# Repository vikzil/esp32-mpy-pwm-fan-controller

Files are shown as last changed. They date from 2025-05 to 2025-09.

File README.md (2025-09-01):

# esp32-mpy-pwm-fan-controller
MQTT-Enabled PWM Fan Controller with 6 Thermistor sensors and MicroPython on ESP32

# Disclamer
I am a hobbyist and not a professional when it comes to electronics or programming. While I try to ensure accuracy, there may be mistakes or suboptimal choices in my work. Please use this as a learning resource, and feel free to offer corrections or suggestions for improvement!

# Background
The purpose of this repository is to document, share, and hopefully polish over time an ESP32-based MicroPython PWM fan controller using thermistors. I created this project to monitor the temperatures of up to six hard drives in my DIY NAS.

In most PCs, fans are controlled based on CPU or GPU temperatures, but that’s not ideal for managing HDD temperatures. In my NAS, the drives usually idle cool, but during operations like scrubs or backups—where several terabytes of data are read continuously—they start heating up. That’s where this controller comes in: it monitors HDD temps and ramps up dedicated fans as needed to keep them in a safe range.

The system publishes fan duty, RPM, and temperature readings over MQTT, allowing integration with platforms like Home Assistant for monitoring and automation.

# Schematics
[Fritzing schematic file](schematics/schematics.fzz)

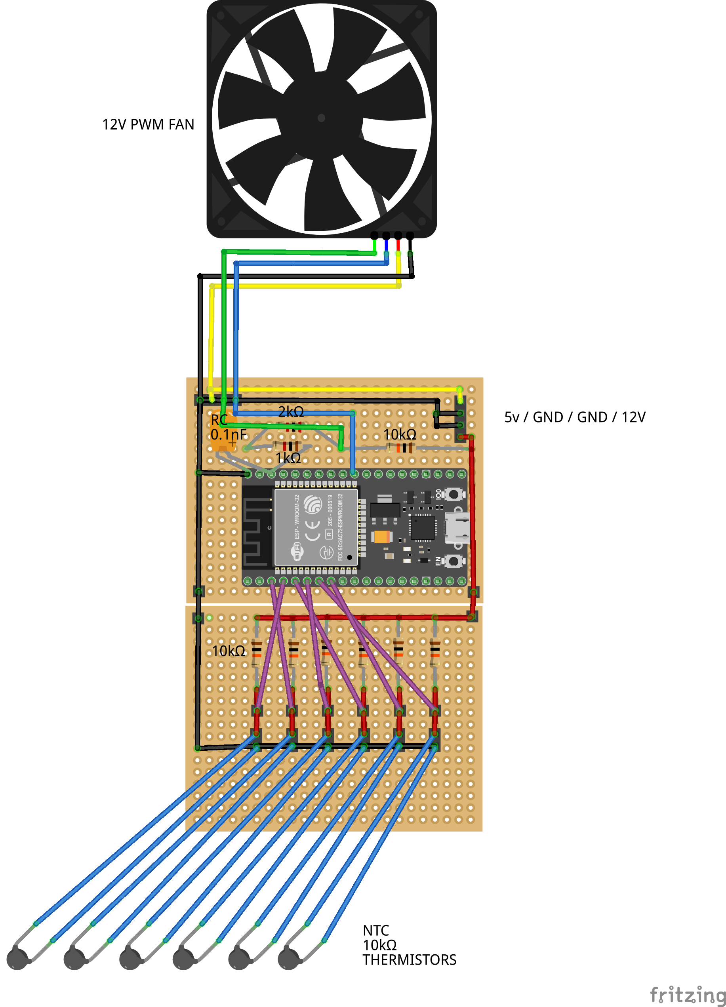
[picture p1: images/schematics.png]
[](images/schematics.png)

# Parts list
* 1× ESP32 controller
* 1× 12V PWM fan (additional fans can be chained if they have compatible connectors)
* 6× 10kΩ NTC thermistor temperature sensors
* 7× 10kΩ resistors
* 1× 2kΩ resistor
* 1× 1kΩ resistor
* 1× 0.1 nF ceramic capacitor
* 1× 4-pin male fan connector
* 1× 4-pin male power supply connector (3-pin could also be used)
* 2× 18×24 hole prototyping PCB boards
* 1× SATA to Molex power adapter (Molex connector removed and wired directly to PCB power input)
* 24 AWG wire
* 1x aluminium tape (I believe it helps with heat transfer between hdd and sensor)

Comments:
* **Casing:** A casing is useful to facilitate handling the fully assembled project and prevent accidental shorts. I used an old external HDD casing, filled it with construction adhesive, and glued the assembled PCBs into it. After that, I waited a couple of weeks to ensure the adhesive had fully dried.
* **USB Access:** I had to cut one edge of the casing to connect a USB cable to the ESP32 for testing. This would have been easier to do before assembling the project.
* **Wires for Sensors:** For attaching the sensors, I used approximately 1m-long wires to ensure the sensors could reach anywhere in the PC case. However, with six sensors, the wires became quite a mess. It might have been smarter to use thinner wires and add connectors to the PCB so sensors not in use could be easily detached.
* **ESP32 Reset:** It would also have been helpful to include a cable with a reset button to easily reset the ESP32 without needing to restart the PC (if powered via SATA, as in my case).
* **Placement:** The placement of the project needs consideration. For example, the ESP32 will lose Wi-Fi connectivity if placed inside a metal PC case. It's better to choose a case with at least one plastic or glass side panel for better connectivity.

# Rough assembly, installation and usage outline
## Install micropython on ESP32
There are several ways to do this, but I used Thonny. A good guide can be found here:

[Getting started with Thonny MicroPython IDE for ESP32](https://randomnerdtutorials.com/getting-started-thonny-micropython-python-ide-esp32-esp8266/)
## Upload scripts to ESP32
Upload the following files to your ESP32: boot.py, main.py, secrets.py, settings.py, and webrepl_cfg.py.
## Install external library umqtt.simple for mqtt support
You’ll need the umqtt.simple library:

[umqtt.simple on GitHub](https://github.com/micropython/micropython-lib/tree/master/micropython/umqtt.simple)
## Fill out credentials
Open secrets.py on your ESP32 and fill in your credentials (e.g., Wi-Fi and MQTT info).
Open webrepl_cfg.py and set password for webrepl access.
## Test run main.py
You should now be able to run main.py and verify that your ESP32 connects to Wi-Fi and publishes data to MQTT. It should also do this automatically after a reset.
A great tool for troubleshooting mqtt is MQTT Explorer:

[MQTT Explorer](https://mqtt-explorer.com/)
## Assemble project without soldering
Assemble the project on a breadboard without soldering according to parts list and schematic, and make sure it works. In this step you should basically be able to get a fully functional controller.

⚠️ Warning: Before powering the project, double-check all wiring and polarities. A wrongly connected 12V line can easily fry the ESP32 or other components.
## Solder everything and install it into casing
Solder everything together and test. Install fully working controller into a casing. Install it into pc and connect temperature sensors to hdds or whatever it is you want to monitor. Connect PWM fan that should react to temperature changes. 
## (Optional) Monitor PWM Fan Duty, Fan RPM and temperature sensor readings in Home Assistant
Home Assistant should be able to autodiscover the sensors, and you can add then to a dashboard. In my case I currently only have two HDDs that I monitor with pins 33 and 39, the rest of the sensors just lie on the bottom of pc case. Also RPM readings worked initially but stopped working after a while, not quite sure why.

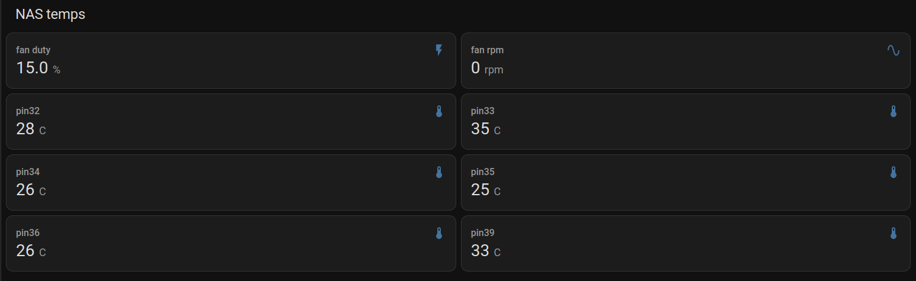
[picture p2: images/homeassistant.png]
[](images/homeassistant.png)

## (Optional) Adjust values in settings.cfg and upload it to ESP32
It's very easy to adjust the PWM fan duty based on temperature while testing the ESP32 in Thonny over USB. However, this becomes more difficult once the controller is deployed in its final location.

The idea is to connect to the controller via WebREPL over Wi-Fi, download the current settings.cfg, modify the values, and upload the file back to the ESP32. After that, simply restart the ESP32 and it should use the updated settings.

[Webrepl over WiFi - Micropython Docs](https://docs.micropython.org/en/latest/esp8266/tutorial/repl.html)

When connected to ESP32 via WebRepl, you should also be able to restart ESP32 by issuing following commands:

Ctrl-C to interrupt printout of temperature readings

<pre>import machine</pre>

<pre>machine.reset()</pre>

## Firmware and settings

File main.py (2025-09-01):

# region import libraries
import gc
import network
import uasyncio
import ujson
import math
from umqtt.simple import MQTTClient
from utime import sleep
from machine import ADC, Pin, PWM
import secrets
# endregion

# region constants
BETA = 3950  # Beta value for thermistor
R_REF = 10000  # Reference resistor value
V_SUPPLY = 5.0  # Supply voltage (5V for ESP32)
DELTA_C = 0 # Temperature measurement correction
THERMISTOR_PINS = [32, 33, 34, 35, 36, 39]  # List of thermistor ADC pins
SETTINGS = {    # PWM Duty depending on max temperature
    0:  30,
    10: 34,
    15: 38,
    20: 42,
    30: 43,
    40: 44,
    50: 45,
    60: 46,
    70: 47,
    80: 48,
    90: 49,
    100: 50
}
# endregion

# Global variables
fan = PWM(Pin(5))  # Fan PWM control
thermistor_temps = {}  # To store temperatures for each pin
temp_C_max = 40  # Initial max temperature
duty = 33.3  # Initial duty cycle
RPM_PIN = 23  # Change if using a different GPIO pin
pulse_count = 0 # Initial pulse count 
rpm = 0 # Initial rpm count


# Initialize thermistors
thermistors = [ADC(Pin(pin, Pin.IN)) for pin in THERMISTOR_PINS]
for t in thermistors:
    t.atten(ADC.ATTN_11DB)  # Set attenuation for full range (0-3.3V)

# Initialize fan
fan.duty(int(duty) * 1023 // 100)  # Initial duty cycle

# Initialize rpm pin with pull-up resistor manually
rpm_sensor = Pin(RPM_PIN, Pin.IN, pull=Pin.PULL_UP)





# region fan control
def set_duty(temp):
    global duty, SETTINGS
    if temp < SETTINGS[0]:
        newduty = 0
    elif temp > SETTINGS[100]:
        newduty = 100
    else:
        items = sorted(SETTINGS.items(), key=lambda item: item[1])
        for i in range(len(items) - 1):
            duty_low, temp_low = items[i]
            duty_upp, temp_upp = items[i + 1]
            if temp_low <= temp <= temp_upp:
                newduty = (duty_low + (temp - temp_low) * (duty_upp - duty_low) / (temp_upp - temp_low))
    if newduty < duty:
        duty = duty - 0.1
        if duty < 0:
            duty = 0
    else:
        duty = newduty
    fan.duty(int(duty) * 1023 // 100)
    print(f">>> Max temp: {temp}°C, setting duty to: {duty}%")
def fan_control():
    set_duty(temp_C_max)
    gc.collect()
# endregion


# region read settings
def read_fan_settings(filename="/settings.cfg"): # try read settings from settings.cfg
    global SETTINGS
    try:
        with open(filename, "r") as f:
            new_settings = {}
            for line in f:
                line = line.strip()
                if "=" in line and not line.startswith("#"):  
                    try:
                        pwm, temp = line.split("=")
                        new_settings[int(pwm)] = int(temp)
                    except ValueError:
                        print(f"Skipping invalid line: {line}")
            if new_settings:
                SETTINGS = dict(sorted(new_settings.items()))
            else:
                print("Invalid file format. Using defaults.")
    except OSError:
        print("Error: settings.cfg not found. Using defaults.")
    
    gc.collect()
# endregion


# region thermistor readings
async def read_temps():
    global temp_C_max
    while True:
        temperatures = []
        for i, thermistor in enumerate(thermistors):
            pin = THERMISTOR_PINS[i]
            voltage = thermistor.read_uv() / 1_000_000
            resistance = R_REF * voltage / (V_SUPPLY - voltage) if voltage > 0 else float("inf")
            try:
                temp_K = 1 / ((math.log(resistance / R_REF) / BETA) + (1 / (273.15 + 25)))
                temp_C = temp_K - 273.15 + DELTA_C
            except ValueError:
                temp_C = 40 # If math fails assume temp 40C
            
            thermistor_temps[pin] = int(temp_C)
            temperatures.append(temp_C)

        print(thermistor_temps)
        temp_C_max = max((t for t in thermistor_temps.values() if t is not None), default=40)
        
        fan_control()
        await uasyncio.sleep(1)  # Sleep to yield control
# endregion


# region wifi connect
async def wifi_connect():
    sta_if = network.WLAN(network.STA_IF)
    while True:    
        if not sta_if.isconnected():
            print('Connecting to network...')
            sta_if.active(False)
            await uasyncio.sleep(60)
            sta_if.active(True)
            sta_if.connect(secrets.WIFI_SSID, secrets.WIFI_PWD)
            
        if sta_if.isconnected():
            print('Network config:', sta_if.ifconfig())
        
        await uasyncio.sleep(60)
# endregion

# region mqtt publish

async def mqtt_publish():
    sta_if = network.WLAN(network.STA_IF)
    global duty, rpm
        
    # Wait for WiFi connection
    while not sta_if.isconnected():
        print("Waiting for WiFi...")
        await uasyncio.sleep(30)

    mqtt_client = MQTTClient("esp32_client", secrets.MQTT_SRV, user=secrets.MQTT_USR, password=secrets.MQTT_PWD)
    try:
        mqtt_client.connect()
        print("Connected to MQTT broker")
        
        while True:
            if sta_if.isconnected():
                # Publish fan frequency, rpm
                discovery_topic = f"homeassistant/sensor/tnas_fan_rpm/config"
                discovery_payload = {
                    "name": f"Truenas tnas_fan_rpm sensor",
                    "state_topic": f"homeassistant/sensor/tnas_fan_rpm/freq",
                    "unique_id": f"tnas_fan_rpm",
                    "expire_after": 60,
                    "state_class": "measurement"
                }
                discovery_message = ujson.dumps(discovery_payload)
                mqtt_client.publish(discovery_topic, discovery_message)
                mqtt_client.publish(f"homeassistant/sensor/tnas_fan_rpm/freq", str(int(rpm)))
                print(f"Published tnas_fan_rpm temp: {int(rpm)} rpm")
                await uasyncio.sleep(0.1)


                # Publish initial availability status
                mqtt_client.publish(f"homeassistant/sensor/tnas_fan_duty/availability", "online")
                # Publish fan pwm duty, %
                discovery_topic = f"homeassistant/sensor/tnas_fan_duty/config"
                discovery_payload = {
                    "name": f"Truenas tnas_fan_duty sensor",
                    "state_topic": f"homeassistant/sensor/tnas_fan_duty/pwr",
                    "unit_of_measurement": "%",
                    "device_class": "power_factor",
                    "unique_id": f"tnas_fan_duty",
                    "expire_after": 60
                }
                discovery_message = ujson.dumps(discovery_payload)
                mqtt_client.publish(discovery_topic, discovery_message)
                mqtt_client.publish(f"homeassistant/sensor/tnas_fan_duty/pwr", str(duty))
                print(f"Published tnas_fan_duty: {duty}%")
                await uasyncio.sleep(0.1)

                # Publish thermistor data
                for key, temp in thermistor_temps.items():
                    discovery_topic = f"homeassistant/sensor/tnas_pin{key}/config"
                    discovery_payload = {
                        "name": f"Truenas pin{key} sensor",
                        "state_topic": f"homeassistant/sensor/tnas_pin{key}/temp",
                        "unit_of_measurement": "\u00B0C",  # safer than literal "°C"
                        "device_class": "temperature",
                        "unique_id": f"tnas_pin{key}_temp",
                        "expire_after": 60
                    }
                    discovery_message = ujson.dumps(discovery_payload)
                    mqtt_client.publish(discovery_topic, discovery_message.encode("utf-8")) # must encode in UTF-8 for it to work
                    mqtt_client.publish(f"homeassistant/sensor/tnas_pin{key}/temp", str(temp))
                    print(f"Published tnas_pin{key} temp: {temp}°C")

                gc.collect()
                await uasyncio.sleep(0.8)


            else:
                print("No WiFi, reconnecting...")
                await uasyncio.sleep(30)
                
    except OSError as e:
        print(f"MQTT Error: {e}")
        await uasyncio.sleep(30)  # Retry after delay
        uasyncio.create_task(mqtt_publish())  # Restart function if MQTT fails  
        await uasyncio.sleep(30)
# endregion

# region rpm read
def rpm_interrupt(pin):
    global pulse_count
    pulse_count += 1  # Count each falling edge

rpm_sensor.irq(trigger=Pin.IRQ_FALLING, handler=rpm_interrupt)

async def measure_rpm():
    global pulse_count
    global rpm
    while True:
        rpm = (pulse_count / 2) * 60  # Convert to RPM (assuming 2 pulses per rev)
        print(f"Fan Speed: {int(rpm)} rpm")
        pulse_count = 0
        await uasyncio.sleep(1)
# endregion


# region event loops
def start_event_loops():
    event_loop = uasyncio.get_event_loop()
    event_loop.create_task(wifi_connect())
    event_loop.create_task(read_temps())
    event_loop.create_task(mqtt_publish())
    event_loop.create_task(measure_rpm())
    event_loop.run_forever()
# endregion

# region main
if __name__ == "__main__":
    read_fan_settings()  # Read fan settings on startup
    start_event_loops()  # Start the asynchronous event loop
# endregion

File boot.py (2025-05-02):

import network
import time
import webrepl
import secrets  # Assuming secrets contains WIFI_SSID and WIFI_PWD

def connect_wifi():
    # Initialize the station interface
    sta_if = network.WLAN(network.STA_IF)
    sta_if.active(True)

    # Connect to the Wi-Fi network
    print("Connecting to WiFi...")
    sta_if.connect(secrets.WIFI_SSID, secrets.WIFI_PWD)

    # Wait until the connection is established
    max_retries = 10
    retries = 0
    while not sta_if.isconnected():
        if retries >= max_retries:
            print("Failed to connect to WiFi, retrying...")
            retries = 0  # Reset retries for the next attempt
        time.sleep(1)
        retries += 1

    # Once connected, print the IP address
    print("Connected to WiFi, IP address:", sta_if.ifconfig()[0])
    
    webrepl.start()

# Call the function to connect to Wi-Fi
connect_wifi()

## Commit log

2025-05-03 Documented settings.cfg with explanations
    [settings.cfg]
2025-09-01 Fixed units of measurement to match https://developers.home-assistant.io/docs/core/entity/sensor/#properties
    [main.py]
